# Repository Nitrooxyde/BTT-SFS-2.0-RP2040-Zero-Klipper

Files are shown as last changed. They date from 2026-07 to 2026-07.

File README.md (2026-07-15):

# BTT SFS 2.0 + RP2040‑Zero — Standalone USB Filament Sensor for Klipper







A **self‑contained, plug‑and‑play filament sensor module** for any Klipper printer:
a **BigTreeTech Smart Filament Sensor (SFS) 2.0** read by a **Waveshare RP2040‑Zero**
flashed as a standard **Klipper USB MCU**, both housed in a **one‑piece printed
receptacle**. One USB cable in, two native Klipper sensor objects out.

The SFS 2.0 exposes two signals — a **runout switch** (filament present / absent) and
a **motion encoder** (~1 pulse / 2.88 mm of filament travel). The RP2040‑Zero turns
both into first‑class Klipper objects:

- `[filament_switch_sensor sfs_switch]` → filament presence
- `[filament_motion_sensor sfs_motion]` → movement / no‑movement (clog, slip)

**Printed part also published on:**
[Printables](https://www.printables.com/model/1781579-btt-sfs-20-rp2040-zero-receptacle) ·
[Cults3D](https://cults3d.com/fr/mod%C3%A8le-3d/divers/standalone-usb-filament-sensor-for-klipper-btt-sfs-2-0-rp2040-zero-receptacl)

---

## Why a dedicated USB MCU for a filament sensor?

The usual way to wire an SFS is two signal lines back to the main board. Giving the
sensor **its own $3 microcontroller on USB** instead has real advantages:

- **Zero pins needed** on your main or toolhead board — useful when they're full,
  or when you don't want to run signal wires across the printer.
- **Board‑agnostic** — no board‑specific headers, voltage rails or pin mappings to
  figure out; the module brings its own MCU and its own 3.3 V, and works the same
  on every printer.
- **Plug‑and‑play** — one USB cable. Move the module between machines, or add it to
  a printer that was never wired for it.
- **Electrically self‑contained** — the SFS is powered from the Pico's 3V3 pin;
  no shared rails, no level‑shifting questions.
- **A single printed part** — sensor + MCU + mounting = one module on a 2020
  extrusion.

What you do with the two signals is up to your config — they are ordinary Klipper
sensor objects:

- **pause on runout** (`pause_on_runout: True` when you're ready),
- **clog / jam detection** — extruder commanded to move, encoder says nothing moves,
- **slip / under‑extrusion detection** — commanded‑vs‑wheel differential,
- **feed verification inside your own macros** — the motion state keeps updating
  even when the sensor is disabled (verified in Klipper source), which makes it a
  clean *“is filament actually moving?”* probe for any custom automation
  (multi‑material feeds, load/unload sequences, whatever you build).

---

## What's in this repo

| Path | Contents |
|---|---|
| [`docs/01-hardware.md`](docs/01-hardware.md) | SFS 2.0 + RP2040‑Zero specs, verified dimensions, BOM |
| [`docs/02-wiring.md`](docs/02-wiring.md) | SFS → Pico wiring, **the 3V3 rule**, pin map |
| [`docs/03-firmware-flashing.md`](docs/03-firmware-flashing.md) | Building & flashing Klipper on the RP2040‑Zero (Katapult) |
| [`docs/04-klipper-integration.md`](docs/04-klipper-integration.md) | `printer.cfg` blocks, safe bring‑up, usage |
| [`docs/05-cad-bracket.md`](docs/05-cad-bracket.md) | The printed receptacle: features, print settings, source |
| [`klipper/sfs.cfg`](klipper/sfs.cfg) | Ready‑to‑`[include]` Klipper config snippet |
| [`cad/SFS_Support_2020.stl`](cad/SFS_Support_2020.stl) | Print‑ready one‑piece receptacle (SFS 2.0 + RP2040‑Zero), definitive |
| [`cad/SFS20_Support_V4.FCStd`](cad/SFS20_Support_V4.FCStd) | FreeCAD source (direct modelling, not parametric — for adjustments) |
| [`firmware/`](firmware/) | Notes on the stock‑Klipper RP2040 build (no custom C) |

---

## Quick start (TL;DR)

1. **Print** `cad/SFS_Support_2020.stl` (ABS/ASA, 4 walls, 0.2 mm — see
   [docs/05](docs/05-cad-bracket.md)). Seat the pico in its cavity and **hot‑glue it
   at the four corners** — that's the retention method, and it doesn't move.
2. **Flash** the RP2040‑Zero with **stock Klipper, RP2040, USB, Katapult bootloader**
   ([docs/03](docs/03-firmware-flashing.md)).
3. **Wire** SFS → Pico: **VCC → 3V3 (never 5V)**, GND → GND, motion → **GP0**,
   switch → **GP1** ([docs/02](docs/02-wiring.md)).
4. **Add** the config below to `printer.cfg` (or copy `klipper/sfs.cfg` next to it
   and `[include sfs.cfg]`), fix the serial to *your* board, `FIRMWARE_RESTART`.

```ini
[mcu sfs]
serial: /dev/serial/by-id/usb-Klipper_rp2040_XXXXXXXXXXXXXXXX-if00

[filament_motion_sensor sfs_motion]
switch_pin: ^sfs:gpio0        # GREEN wire — motion encoder
detection_length: 2.88        # mm; SFS theoretical pulse pitch — tune at the bench
extruder: extruder
pause_on_runout: False        # bring-up safe: observe first, arm later

[filament_switch_sensor sfs_switch]
switch_pin: ^sfs:gpio1        # BLUE wire — runout switch
pause_on_runout: False
```

> ⚠️ **The two golden rules** (details in the docs):
> 1. **Power the SFS at 3.3 V.** The RP2040 is **not** 5 V‑tolerant (~3.8 V abs max).
>    5 V on the signal lines destroys the Pico.
> 2. **Keep the `^` pull‑ups.** The SFS outputs are open‑collector / switch‑to‑ground;
>    without an internal pull‑up they float.

---

## Placement

Anywhere on the filament path — that's the point of a self‑contained module. One
practical rule: **the closer to the extruder, the less slack** between the encoder
wheel and the drive gear, so the tighter `detection_length` can be and the earlier a
real clog or runout is flagged. And fit the **PTFE ID2/OD4 guide all the way into the
SFS bore on both ports** — without it, pushed filament buckles at the junction
(empirically confirmed; see [docs/01](docs/01-hardware.md)).

---

## Status

**Functional.** Built and running on a Voron 2.4: the receptacle prints and fits, the
RP2040‑Zero runs stock Klipper over USB (Katapult in place — no BOOT button needed for
reflash), and both sensor objects run in Klipper with the SFS powered at 3V3. The
definitive STL isn't claimed perfect — the pico is simply **hot‑glued at its four
corners** and doesn't move; a couple of optional refinements remain listed in
[docs/05](docs/05-cad-bracket.md).

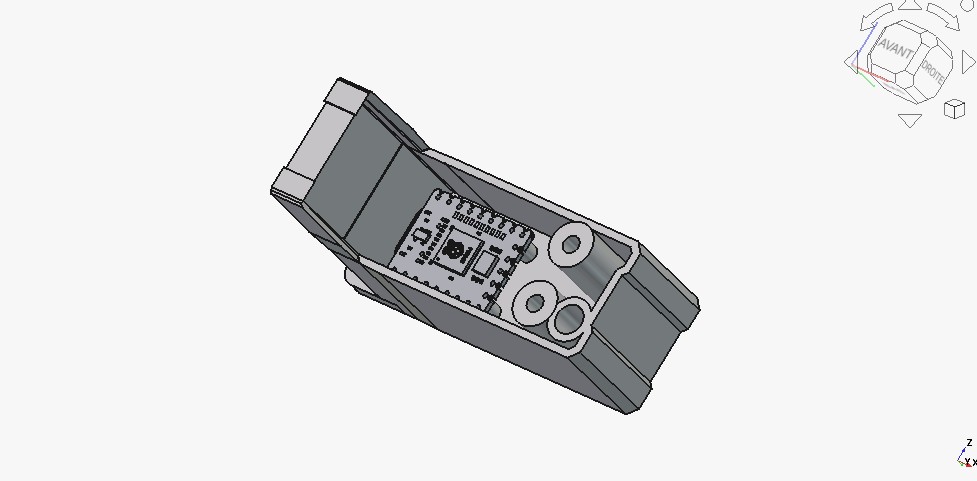
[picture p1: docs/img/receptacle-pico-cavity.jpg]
Receptacle with the RP2040-Zero seated in its cavity


See [`CHANGELOG.md`](CHANGELOG.md) for the build history.

---

## License

MIT — see [`LICENSE`](LICENSE). The BTT SFS 2.0 CAD model referenced in the docs is
BigTreeTech's own, distributed from their
[smart‑filament‑detection‑module](https://github.com/bigtreetech/smart-filament-detection-module)
repository under their terms.

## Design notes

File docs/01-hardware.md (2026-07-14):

# 01 — Hardware & specifications

## Bill of materials

| Qty | Part | Notes |
|-----|---|---|
| 1 | **BigTreeTech Smart Filament Sensor (SFS) 2.0** | Owned. Runout switch + motion encoder in one body. |
| 1 | **Waveshare RP2040‑Zero** | The USB MCU. 18 × 23.5 mm. **Not 5 V‑tolerant.** |
| 1 | Printed receptacle | `cad/SFS_Support_2020.stl` — houses both parts as one piece. |
| — | Hot glue | Fix the RP2040‑Zero in its cavity at the four corners. |
| 2 | **PC4‑M6** pneumatic fittings | Supplied with the SFS; one at each filament port. |
| 1 | **PTFE tube ID2 / OD4** | **Mandatory** guide into the SFS bore (see below). |
| 2 | **M3×12 button‑head** screws | Fix the receptacle to the SFS mounting face (self‑tapping into the SFS). The receptacle's counterbores are sized for button heads; the M3×6 supplied by BTT are too short through the receptacle. |
| 2 | M3 screws + T‑nuts | Fix the receptacle's tab to a 2020 extrusion. |
| 1 | USB‑C cable | RP2040‑Zero → Raspberry Pi. |
| — | Dupont / JST‑to‑bare wiring | SFS's two 3‑pin leads → RP2040‑Zero pads. |

> The BTT SFS 2.0 ships with 3× M3×6 screws, 2× PC4‑M6, and a PTFE ID2/OD4/L30 tube.

---

## BTT SFS 2.0 — verified specifications

Cross‑checked three ways: live measurement of the official STEP in FreeCAD ==
BTT STEP == BTT manual (`SFS V2.0 …_20231123.pdf`).

### Mechanical
- **Body:** X 53.5 · Y 30.3 · Z 27.3 mm (BTT official: 53.1 × 30.3 × 27.3). ~36 g.
- **Mounting face:** the large 53 × 27 face (normal +Y; net measured face area
  ≈ 1054 mm² — less than 53 × 27 because of the cutouts in the face).
- **3× M3 self‑tapping holes** in that face (pilot Ø2.7, head counterbore ≈ Ø5,
  blind into the plastic — **no inserts**; BTT supplies 3× M3×6):

  | Hole | X (mm) | Z (mm) |
  |------|--------|--------|
  | H1 | −61.7 | +6.7 |
  | H2 | −37.0 | +6.7 |
  | H3 | −37.0 | −5.7 |

  Spacing (BTT manual): **24.7 mm × 12.4 mm**, L‑shaped pattern.

- **Filament path = X axis** (inline pass‑through, bidirectional, 1.75 mm).
  M6 ports at **both ends** (accept the 2× PC4‑M6). The two ports are **diagonally
  offset** (the filament routes around the encoder): Port A ≈ (Y 22.0, Z +6.3),
  Port B ≈ (Y 36.9, Z −6.3). Internal bore: Ø1.75 guide → Ø3.4 groove → Ø4.6/5.0
  PTFE seat.

### The PTFE guide is not optional (empirically confirmed)
On **push** (loading), any un‑guided gap between the fitting and the internal bore
becomes a **buckling point** — the filament escapes at the junction instead of
advancing. Adding the **PTFE ID2/OD4 tube all the way into the internal bore** (not
just seated in the PC4‑M6) unblocked pushing in real use. Invisible on **pull**
(unloading), so easy to under‑estimate at design time — **fit it on both ports.**

### Electrical — **read this before wiring**
- **Rated voltage: 3.3 V – 5 V ONLY.** The manual (p.5 *Specifications*; p.25
  *Caution*) is explicit: *“any higher voltage will cause damage.”*
  → **The SFS works officially at 3.3 V** — the "5V" label on BTT's wiring diagrams
  is because their host boards are STM32 (5 V rail + 5 V‑tolerant FT pins), **not**
  a power‑supply requirement.
- **Detection length:** 2.88 mm (theoretical) per encoder pulse.
- **Cable:** 100 cm Y‑cable — 1× **4‑pin** at the sensor → 2× **3‑pin** to the board.
- **Wire colours / signals:**

  | Colour | Signal | Notes |
  |--------|--------|-------|
  | **RED** | VCC | **Feed 3.3 V for the RP2040** (see wiring). |
  | **BLACK** | GND | |
  | **BLUE** | Switch / runout | Active‑low, **pull‑up required**. |
  | **GREEN** | Motion / encoder | Toggles ~1 pulse / 2.88 mm, **pull‑up required**. |

  Both outputs behave as **switch‑to‑ground / open‑drain** → an **MCU pull‑up is
  mandatory** (the RP2040's internal pull‑ups do the job, hence the `^` prefix in
  the Klipper config).

- **On‑board LEDs** (on the label face): red = empty; blue blinking = extrusion OK;
  blue solid / off = no movement. Detection is internal (no external optical window).

> **Not documented / confirm visually if you rebuild the cable:** the exact JST
> series of the 4‑pin (XH 2.54 vs PH 2.0) and the exact cable‑exit face/orientation.

### Official CAD / manual
BigTreeTech repo: [`bigtreetech/smart-filament-detection-module`](https://github.com/bigtreetech/smart-filament-detection-module)
- `/V2.0/CAD/SFS V2.0 Model.STEP` (the model used to design the receptacle)
- `/V2.0/CAD/SFS V2.0 Bracket for Hurakan.STEP` (BTT's own reference bracket)
- `/V2.0/STL`, `/V2.0/Manual/… _20231123.pdf`

The STEP model was kept locally at `Voron/SFS_V2_0/SFS V2.0 Model.STEP` (≈25 MB, not
bundled here to keep the repo lean).

---

## Waveshare RP2040‑Zero — specifications

- PCB **18 × 23.5 × ~1.6 mm**, **USB‑C** on a short edge.
- RP2040 + 2 MB flash, WS2812 (NeoPixel) LED + power LED, **BOOT/RESET** button.
- 9 castellated pads per side + through‑pads.
- **Logic 3.3 V. NOT 5 V‑tolerant** (RP2040 absolute max ≈ 3.8 V on any pin).
  This is *the* reason the SFS must be powered at 3.3 V here.

> The RP2040‑Zero STEP found online (`crides/kleeb`) has **11 mm male header pins**
> (a low‑profile keyboard variant) — those are a modelling artifact; the real Zero is
> ~1.6 mm bare. They were ignored when designing the receptacle.

### Third RP2040 on the rig — serial hygiene
This Pico is the **third** RP2040 Klipper MCU on the printer (after the **BTT Eddy**
and the **Fysetc PIS**). All three share VID:PID `1d50:614e` (Manufacturer "Klipper",
Product "rp2040"). **Always identify each board by its unique serial** before editing
a `[mcu …]` block — see [docs/03](03-firmware-flashing.md).

Known serials on the reference rig:
- Octopus Pro (STM32): `usb-Klipper_stm32f446xx_300025001350324E31333220-if00`
- BTT Eddy (RP2040 #1): `usb-Klipper_rp2040_504450593844A21C-if00`
- Fysetc PIS (RP2040 #2): `usb-Klipper_rp2040_E663B03597314E27-if00`
- **This SFS Pico (RP2040 #3): `usb-Klipper_rp2040_5303284738FB5E1C-if00`**

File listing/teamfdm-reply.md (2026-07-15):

# TeamFDM reply — thread #6534 "BTT SFS 2.0 with Leviathan mainboard"

> À poster en réponse au thread (compte user). Ton : partage d'une alternative,
> humble. La réponse est AUTOSUFFISANTE (tout le how-to inline) ; le repo n'est
> qu'un pointeur final.
> https://www.teamfdm.com/forums/topic/6534-btt-sfs-20-with-leviathan-mainboard/

---

Nice find with PC0/PC1 + the neopixel 5V — glad it works.

For anyone landing here who'd rather not deal with board-specific pins and rails
at all, here's another route that works on any printer: give the sensor **its own
MCU**. A Waveshare **RP2040-Zero** (~$3) flashed as a plain Klipper USB MCU reads
both SFS signals, and the mainboard isn't involved at all — one USB cable to the
Pi.

**1. Flash the pico** — stock Klipper, nothing custom:

```
make menuconfig   # Micro-controller: Raspberry Pi RP2040 · Communication: USB
make
```

Hold BOOT, plug USB → the pico mounts as an `RPI-RP2` drive → copy
`out/klipper.uf2` onto it. Done. (Optional: put Katapult under it so future
reflashes don't need the button.)

**2. Wire the SFS to the pico** — 4 wires:

| SFS wire | → pico |
|---|---|
| RED (VCC) | **3V3** |
| BLACK (GND) | GND |
| GREEN (motion) | GP0 |
| BLUE (switch) | GP1 |

Power it from the pico's **3.3 V** pin: the SFS is rated 3.3–5 V per the BTT
manual (p.5 — the "5V" in BTT's wiring diagrams is just because their example
boards are 5V-tolerant STM32s), and the RP2040 itself is *not* 5V-tolerant, so
3.3 V keeps every signal safe whatever the output topology is. This also
sidesteps the diode-drop / sagging-rail questions entirely — the pico's 3V3
comes regulated from USB.

**3. Klipper config:**

```ini
[mcu sfs]
serial: /dev/serial/by-id/usb-Klipper_rp2040_XXXX-if00

[filament_motion_sensor sfs_motion]
switch_pin: ^sfs:gpio0        # motion encoder — clog/slip detection
detection_length: 2.88        # SFS pulse pitch; raise if false triggers
extruder: extruder
pause_on_runout: False        # observe first in Mainsail, arm later

[filament_switch_sensor sfs_switch]
switch_pin: ^sfs:gpio1        # runout switch
pause_on_runout: False
```

The `^` pull-ups are mandatory (both SFS outputs are switch-to-ground). Bring it
up with `pause_on_runout: False`, watch the two sensors in Mainsail while you
poke filament in and out, then arm the pause once you trust it. One gotcha if
you already have other RP2040s (Eddy, PIS…): they all share the same USB
VID:PID, so identify the right `/dev/serial/by-id/` entry by unplugging the pico
and seeing which one disappears.

I also designed a one-piece printed receptacle that holds the SFS + pico
together and mounts on a 2020 extrusion — that plus the full write-up
(flashing with Katapult, bring-up, assembly) is here if useful:
GitHub `Nitrooxyde/BTT-SFS-2.0-RP2040-Zero-Klipper` · Printables model 1781579.
Free/open (MIT + CC-BY), my own project.

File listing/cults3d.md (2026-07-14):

# Fiche Cults3D — prête à coller

> Fichiers à uploader : `cad/SFS_Support_2020.stl`
> Images : `docs/img/receptacle-pico-cavity.jpg`, `docs/img/receptacle-usbc-opening.jpg`
> **+ recommandé : 2–3 photos réelles** (pièce imprimée, module monté sur le 2020, câblage) — les photos réelles font ×3 sur les téléchargements.
> Catégorie : **Outil → Accessoires pour imprimante 3D**
> Prix : Gratuit (suggestion) · Licence : à choisir (suggestion : CC BY 4.0 — cohérent avec le repo MIT)

---

## Titre (FR)

Capteur de filament USB autonome pour Klipper — support BTT SFS 2.0 + RP2040-Zero

## Titre (EN)

Standalone USB Filament Sensor for Klipper — BTT SFS 2.0 + RP2040-Zero receptacle

---

## Description (FR)

**Un module capteur de filament complet, autonome, en une seule pièce imprimée — un câble USB et c'est branché.**

Ce support monobloc loge un **BigTreeTech Smart Filament Sensor 2.0** et un **Waveshare RP2040-Zero** flashé en MCU Klipper USB. Le pico lit les deux signaux du SFS (présence + mouvement) et les expose à Klipper comme objets natifs :

- `filament_switch_sensor` → présence du filament (runout)
- `filament_motion_sensor` → mouvement réel (bourrage, glissement, sous-extrusion)

**Pourquoi un MCU dédié ?**
- **Zéro pin nécessaire** sur votre carte principale ou toolhead
- **Un seul câble USB** — pas de fils de signaux à tirer à travers l'imprimante
- **Plug-and-play** : déplaçable d'une machine à l'autre
- Électriquement autonome : le SFS est alimenté en 3,3 V par le pico

**Caractéristiques du support :**
- Fixation sur **profilé 2020** (patte avec 2 trous M3 pour écrous T)
- Se visse sur la face de montage du SFS (2× M3×12 tête bombée, lamages intégrés)
- Cavité pour le RP2040-Zero avec ouverture USB-C au contour du connecteur
- Accès aux boutons BOOT/RESET (trous oblongs 3×5 mm)
- 2 ports filament M6 pour raccords PC4-M6

**Assemblage :** le pico se colle à la **colle chaude aux 4 coins** dans sa cavité (simple, ferme, démontable). Passez les guides PTFE ID2/OD4 jusqu'au fond des ports du SFS (indispensable en poussée).

**⚠️ Câblage : alimentez le SFS en 3,3 V uniquement** (le RP2040 n'est pas tolérant au 5 V). Câblage complet, flash Klipper/Katapult et config prête à l'emploi sur le GitHub :
👉 **github.com/Nitrooxyde/SFS2-RP2040-Klipper**

**Impression :** ABS/ASA (ou PETG), 0,2 mm, 4 périmètres, 30–40 % de remplissage. Supports uniquement sur les ouvertures selon l'orientation. STL vérifié étanche (59 488 facettes). Encombrement : 69 × 48 × 25 mm.

**BOM :** SFS 2.0 · RP2040-Zero · 2× M3×12 tête bombée · 2× M3 + écrous T · 2× PC4-M6 (fournis avec le SFS) · PTFE ID2/OD4 · câble USB-C · colle chaude.

Testé en réel sur une Voron 2.4.

---

## Description (EN)

**A complete, self-contained filament sensor module in a single printed part — one USB cable and you're wired.**

This one-piece receptacle houses a **BigTreeTech Smart Filament Sensor 2.0** and a **Waveshare RP2040-Zero** flashed as a Klipper USB MCU. The pico reads both SFS signals (presence + motion) and exposes them to Klipper as native objects:

- `filament_switch_sensor` → filament presence (runout)
- `filament_motion_sensor` → actual movement (clog, slip, under-extrusion)

**Why a dedicated MCU?**
- **Zero pins needed** on your main or toolhead board
- **One USB cable** — no signal wires across the printer
- **Plug-and-play**: move it between machines
- Electrically self-contained: the SFS runs on 3.3 V from the pico

**Receptacle features:**
- Mounts on a **2020 extrusion** (tab with 2× M3 holes for T-nuts)
- Screws onto the SFS mounting face (2× M3×12 button-head, counterbores included)
- RP2040-Zero cavity with a USB-C opening cut to the connector contour
- BOOT/RESET button access (3×5 mm oval holes)
- 2× M6 filament ports for PC4-M6 fittings

**Assembly:** hot-glue the pico at its **four corners** in the cavity (simple, firm, serviceable). Run the PTFE ID2/OD4 guides all the way into the SFS bore (mandatory when pushing filament).

**⚠️ Wiring: power the SFS at 3.3 V only** (the RP2040 is not 5 V-tolerant). Full wiring, Klipper/Katapult flashing and a ready-to-include config on GitHub:
👉 **github.com/Nitrooxyde/SFS2-RP2040-Klipper**

**Printing:** ABS/ASA (or PETG), 0.2 mm, 4 walls, 30–40 % infill. Supports only on the openings depending on orientation. STL verified watertight (59,488 facets). Footprint: 69 × 48 × 25 mm.

**BOM:** SFS 2.0 · RP2040-Zero · 2× M3×12 button-head · 2× M3 + T-nuts · 2× PC4-M6 (supplied with the SFS) · PTFE ID2/OD4 · USB-C cable · hot glue.

Tested for real on a Voron 2.4.

---

## Tags

`klipper` `voron` `filament sensor` `runout sensor` `btt sfs` `rp2040` `smart filament sensor` `2020 extrusion` `3d printer accessory` `filament runout`

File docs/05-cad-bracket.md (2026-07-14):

# 05 — The printed receptacle

A **one‑piece receptacle** that holds the **SFS 2.0** and the **RP2040‑Zero** together
and mounts to a **2020 extrusion** — so the whole sensor module is a single printed
part with one USB cable leaving it.

- **Print file:** [`cad/SFS_Support_2020.stl`](../cad/SFS_Support_2020.stl)
  — binary STL, **59 488 facets**, **watertight** (verified: 0 open/non‑manifold
  edges, edges = 1.5 × facets exactly), volume ≈ 13.7 cm³.
- Bounding box: **69.3 mm** (incl. the 2020 tab) × **47.5 mm** × **24.7 mm**.
- **Source:** [`cad/SFS20_Support_V4.FCStd`](../cad/SFS20_Support_V4.FCStd)
  — ⚠️ **direct BREP modelling, not a parametric feature tree**: there are no
  dimensions to edit in a tree. Provided for those who want to adjust the geometry
  by direct modelling.

Receptacle with the RP2040-Zero seated
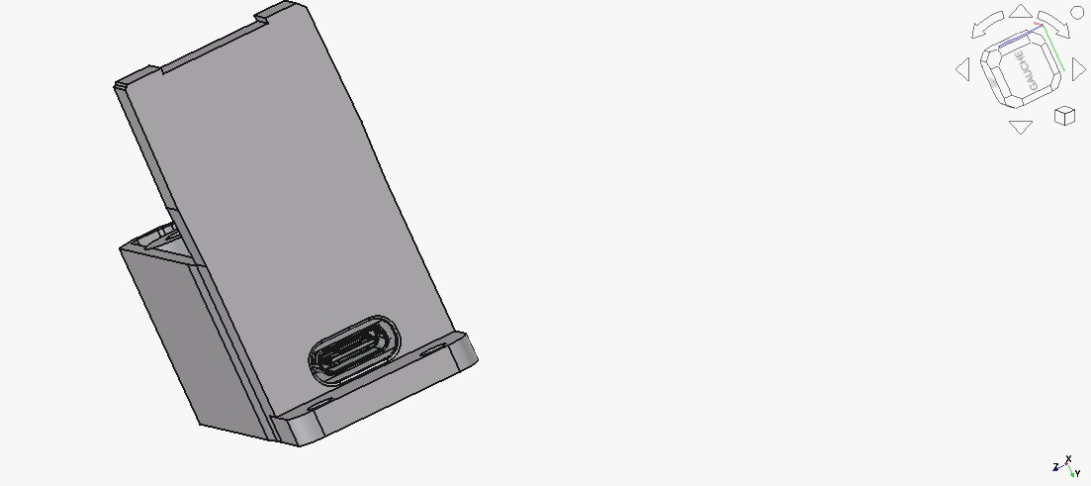
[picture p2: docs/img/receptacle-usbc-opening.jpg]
USB-C opening in the end wall


> Design note: the part was modelled face by face against the real SFS/RP2040 STEP
> geometry (an earlier patch‑on‑patch attempt was scrapped and rebuilt from scratch).

## Features

- **RP2040‑Zero cavity** at the −X end, USB‑C exposed through an opening cut to the
  **real connector contour** (obround; the tight axis is the ~3.4 mm connector
  height — see *Known‑open items* below).
- **2× M6 filament ports** matching the SFS bore, for the PC4‑M6 fittings.
  → Run the **PTFE ID2/OD4** guide all the way into the SFS bore on both
  (see [docs/01](01-hardware.md)).
- **2× M3 mounting tunnels** through the SFS mount face — Ø3.4 clearance shaft with a
  **flat Ø6 counterbore** for M3×12 button‑head screws (button head = flat‑bottom
  counterbore, never a conical countersink), ~6 mm thread engagement into the SFS.
- **2× BOOT/RESET access holes**, **ovalised 3.0 × 5.0 mm**, aligned to the Pico's
  KEY1/KEY2 buttons.
- **4× PCB standoffs**, trimmed to seat exactly on the board's top face
  (**Y = 56.60 mm + 0.10 mm clearance**) — no bottoming‑out on the PCB.
- **Reinforced outer wall ≈ 3.45 mm** for rigidity.
- **2020 mounting tab** on the −X face: extended +20 mm in X, **2× M3 through‑holes**
  for T‑nut mounting to the extrusion.
- Front mouth aligned to a single plane with a small **R0.3 fillet** on the front
  contour edges.

## Suggested print settings

This is a functional structural bracket, so print it strong:

| Setting | Value |
|---|---|
| Material | **ABS or ASA** (matches the toolhead environment; PETG works too) |
| Layer height | 0.2 mm |
| Walls / perimeters | **4** (wall count is the real strength lever, not layer height) |
| Infill | 30–40 % |
| Supports | Only where the USB‑C / port / button openings overhang, depending on orientation |

> Orientation is not prescriptive — pick the face that puts the mounting tab and the
> filament ports on clean surfaces and minimises support inside the pico cavity.

## Assembly

- Seat the RP2040‑Zero in its cavity (USB‑C through the end‑wall opening) and
  **hot‑glue it at the four corners** — that's the designed retention: simple, holds
  firmly, and stays serviceable (hot glue peels off if you ever need the board out).
- Screw the receptacle to the SFS mounting face with the 2× M3×12 button‑heads, and
  to the 2020 extrusion through the tab with M3 + T‑nuts.
- Run the PTFE ID2/OD4 guides into the SFS bore on **both** ports (see
  [docs/01](01-hardware.md)).

## Known‑open items / optional refinements

The part is **functional** (the author: *"it's not perfect"* — but it does the job);
a few optional refinements were deliberately left open:

- **Positive pico retention** — the cavity is open by design; hot glue at the four
  corners is the intended fix (see *Assembly*). Add a clip/lid in the source if you
  want a mechanical retention instead.
- **USB‑C opening clearance** — the truly tight axis is the **connector height**
  (~3.4 mm opening vs ~3.16 mm connector, ≈0.2 mm play); the long axis is already
  ~2× the connector width. If your cable's overmold binds, open the *height* axis
  slightly in the source (an earlier tweak widened the long axis, which changes
  nothing — see `CHANGELOG.md`, 07‑04).
- **−Y mouth flush lip** — a ~0.01 mm residual skin (1/20 of a layer, not sliced) was
  left because OCC refused a perfectly coincident cut; reconstruct the −Y face as a
  separate parametric frame if you want a geometric flush.
- Minor plane‑alignment nits (floor/ceiling ±10.728 vs ±10.7) — cosmetic.

## ⚠️ Maintainer note — regenerating the STL
When rebuilding/exporting from the source: **always re‑read the exported file on disk**
(facet count / size / date) to prove the content before printing — do not trust the
"export succeeded" message alone (a stale STL once got printed for 1h40 this way).
If exporting from a snap‑packaged FreeCAD, note the export lands in the snap sandbox
(`~/snap/freecad/<rev>/…`), not your real home.

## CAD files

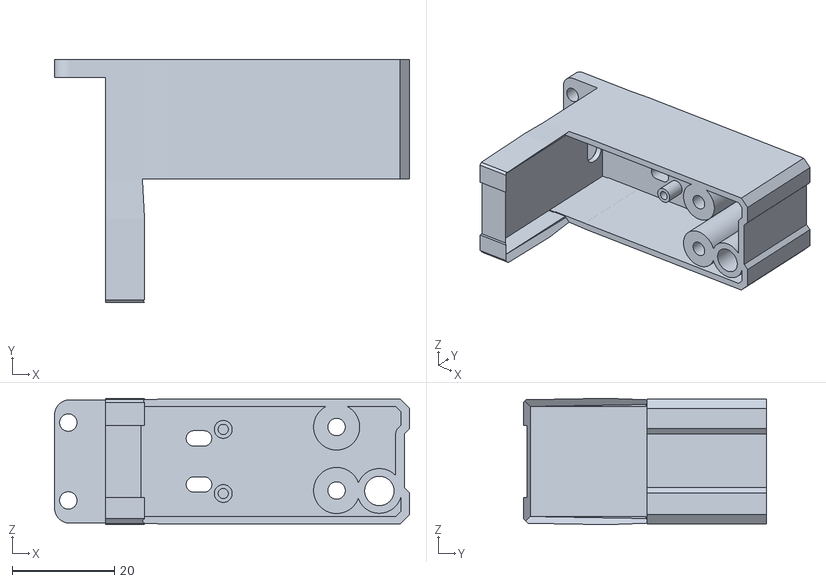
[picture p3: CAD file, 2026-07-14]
cad/SFS_Support_2020.stl
69.3 x 47.5 x 24.7

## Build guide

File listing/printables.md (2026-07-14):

# Printables listing — ready to paste

> Files to upload: `cad/SFS_Support_2020.stl`
> Images: `docs/img/receptacle-pico-cavity.jpg`, `docs/img/receptacle-usbc-opening.jpg`
> **+ recommended: 2–3 real photos** (printed part, module mounted on the 2020, wiring) — real photos massively boost downloads.
> Category: **3D Printers → Printer Accessories**
> License: pick in the dropdown (suggestion: **CC BY 4.0**, consistent with the MIT repo)

---

## Title

Standalone USB Filament Sensor for Klipper — BTT SFS 2.0 + RP2040-Zero Receptacle

## Summary (short field)

One-piece receptacle for a BTT SFS 2.0 + RP2040-Zero running Klipper over USB. One cable in → native runout + motion sensors in Klipper. Zero pins needed on your boards. Mounts on 2020 extrusion.

---

## Description

**A complete, self-contained filament sensor module in a single printed part — one USB cable and you're wired.**

This receptacle houses a **BigTreeTech Smart Filament Sensor 2.0** and a **Waveshare RP2040-Zero** flashed as a standard Klipper USB MCU. The pico reads both SFS signals and exposes them to Klipper as native objects:

- `filament_switch_sensor` → filament presence (runout)
- `filament_motion_sensor` → actual movement (clog, slip, under-extrusion detection)

### Why a dedicated MCU?

- **Zero pins needed** on your main or toolhead board
- **One USB cable** — no signal wires across the printer
- **Plug-and-play** — move it between machines, or retrofit a printer never wired for it
- Electrically self-contained: the SFS runs on 3.3 V from the pico

### Receptacle features

- Mounts on a **2020 extrusion** (tab with 2× M3 holes for T-nuts)
- Screws onto the SFS mounting face — 2× M3×12 button-head, flat counterbores included
- RP2040-Zero cavity with a USB-C opening cut to the real connector contour
- BOOT/RESET button access holes (3×5 mm ovals)
- 2× M6 filament ports for the PC4-M6 fittings supplied with the SFS

### Assembly

1. Seat the pico in its cavity (USB-C through the end-wall opening) and **hot-glue it
   at the four corners** — simple, firm, and serviceable.
2. Screw the receptacle to the SFS with 2× M3×12 button-head.
3. Mount on the 2020 with M3 + T-nuts.
4. Run the **PTFE ID2/OD4 guides all the way into the SFS bore** on both ports —
   mandatory when pushing filament, otherwise it buckles at the junction.

### Wiring & Klipper config

**⚠️ Power the SFS at 3.3 V only** — the RP2040 is **not** 5 V-tolerant.
Motion → GP0, switch → GP1, internal pull-ups.

Full wiring guide, Klipper/Katapult flashing steps and a ready-to-include
`sfs.cfg` are on GitHub:
**https://github.com/Nitrooxyde/SFS2-RP2040-Klipper**

### BOM

| Qty | Part |
|-----|---|
| 1 | BigTreeTech SFS 2.0 |
| 1 | Waveshare RP2040-Zero |
| 2 | M3×12 button-head screws |
| 2 | M3 screws + T-nuts (2020 mounting) |
| 2 | PC4-M6 fittings (supplied with the SFS) |
| — | PTFE tube ID2/OD4 |
| 1 | USB-C cable |
| — | Hot glue |

Tested for real on a Voron 2.4. STL verified watertight (59,488 facets).
Footprint: 69 × 48 × 25 mm.

---

## Print settings (structured fields)

- **Printer:** any (designed on a Voron 2.4)
- **Nozzle:** 0.4 mm
- **Layer height:** 0.2 mm
- **Material:** ABS / ASA (PETG works)
- **Perimeters/walls:** 4
- **Infill:** 30–40 %
- **Supports:** only on the USB-C / port / button openings, depending on orientation
- **Brim:** optional

## Tags

klipper, voron, filament-sensor, runout-sensor, btt-sfs, rp2040, smart-filament-sensor, 2020-extrusion, printer-accessory, filament-runout

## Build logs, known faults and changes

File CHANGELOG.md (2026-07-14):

# Changelog / build history

Chronology of how the SFS 2.0 + RP2040‑Zero USB filament sensor came together
(reference build: Voron 2.4, Raspberry Pi host).

## 2026‑07‑02 — Decision & scope
- Chose to read the **BTT SFS 2.0** with a dedicated **RP2040‑Zero flashed as a
  Klipper USB MCU** — a self‑contained, plug‑and‑play sensor module instead of wiring
  the two signals back to the main board. Two signals →
  `[filament_motion_sensor]` (clog/slip) + `[filament_switch_sensor]` (presence).
- Imported the official **SFS V2.0 Model.STEP** and the RP2040‑Zero model in FreeCAD.
  Cross‑verified SFS dimensions three ways (live measurement == STEP == manual).

## 2026‑07‑02 → 07‑03 — Receptacle CAD
- First bracket attempt (boolean patch‑on‑patch) was **rejected** and the part
  **rebuilt from scratch parametrically**, face by face, as `REC_body_v1` in
  `SFS20_Support_V2.FCStd`.
- Built up: pico cavity, USB‑C opening (real connector contour), 2× M6 filament ports,
  2× M3 mounting tunnels (Ø6 flat counterbore for M3×12 button‑head), 2× BOOT/RESET
  access holes, 4× PCB standoffs, mouth alignment + R0.3 front fillet.

## 2026‑07‑03 — STL exports
- `REC_body_v2.stl` (64 160 facets) exported.
- Later superseded by the re‑exported `REC_body_v1.stl` (see 07‑04).

## 2026‑07‑04 — Firmware, wiring decision, refinements
- **SFS spec verified from the official manual (PDF):** rated **3.3–5 V**, detection
  length **2.88 mm**. Conclusion: power the SFS at **3.3 V** for the (non‑5 V‑tolerant)
  RP2040.
- **Pin mapping decided:** motion → **GP0**, switch → **GP1**, pull‑ups on both.
- **RP2040‑Zero flashed** stock Klipper USB + Katapult →
  serial `usb-Klipper_rp2040_5303284738FB5E1C-if00`. Re‑tested OK.
- Receptacle refined: M3 tunnels' counterbores corrected, outer wall reinforced to
  ~3.45 mm, BOOT/RESET holes ovalised 3.0 × 5.0, PCB standoffs re‑trimmed to seat on
  the board face (Y 56.60 + 0.10 clearance), **2020 mounting tab** added.
- `printer.cfg` bring‑up block prepared (safe mode, `pause_on_runout: False`).
- **`REC_body_v1.stl` re‑exported** (63 536 facets, watertight) — print file at the
  time, since replaced by the definitive `SFS_Support_2020.stl` (see 07‑15).
- USB‑C opening widened by 0.3 mm (commit `elargir_usbc_+0.3`); later noted the
  *tight* axis is the ~3.4 mm connector‑height axis, not the one widened.

## 2026‑07‑05 — Deployed
- **Sensor module deployed on the reference printer at VCC 3.3 V, both sensor objects
  enabled in Klipper.**
- `sfs_motion` confirmed as the *"advances vs slips"* discriminator during manual
  load/unload jogs (its motion state updates even when the sensor is `ENABLE=0`).
- Confirmed empirically: **PTFE ID2/OD4 guide into the SFS bore is mandatory** on push
  (without it the filament buckles at the junction).

## 2026‑07‑15 — Definitive STL
- **`SFS_Support_2020.stl` delivered by the author** with final corrections —
  59 488 facets, watertight (0 open edges), 69.3 × 47.5 × 24.7 mm, ≈ 13.7 cm³.
  Replaces `REC_body_v1.stl`.
- FreeCAD source updated to **`SFS20_Support_V4.FCStd`** (direct BREP modelling,
  not a parametric feature tree — provided for adjustments).
- Retention method settled: the RP2040‑Zero is **hot‑glued at its four corners**
  in the open cavity — simple and it doesn't move.
- CAD screenshots added to `docs/img/`.

## 2026‑07‑15 — This repo
- Consolidated hardware, wiring, firmware, Klipper integration and CAD into a
  standalone, documented repository. Bracket bundled as print‑ready STL + FreeCAD
  source; Klipper config as a ready‑to‑include snippet.
- Documentation reframed: the module is a **generic standalone USB filament sensor** —
  application‑specific context from the reference printer (multi‑material feed
  experiments) removed from the docs; what you build on the two signals is up to
  your config.

---

### Notes on state
- The receptacle is **functional**; the FreeCAD source (`SFS20_Support_V4.FCStd`) and
  the definitive print‑ready STL (`SFS_Support_2020.stl`) are both in `cad/`.
- The config to use is [`klipper/sfs.cfg`](klipper/sfs.cfg) — adapt the serial to your
  board.

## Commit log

2026-07-14 Ship the definitive STL + V4 source + assembly method + screenshots
    - cad/SFS_Support_2020.stl: definitive print file from the author (59488
    facets, verified watertight: 0 open edges, edges=1.5x facets; 69.3x47.5x24.7
    mm, ~13.7 cm3). Replaces REC_body_v1.stl.
    - cad/SFS20_Support_V4.FCStd: updated source; documented as direct BREP
    modelling (not a parametric feature tree), provided for adjustments.
    - Assembly documented: RP2040-Zero hot-glued at its four corners in the open
    cavity (the designed retention — simple, firm, serviceable).
    - docs/img/: two CAD screenshots (pico seated in cavity, USB-C opening),
    referenced from README and docs/05.
    - README/docs/01/docs/05/CHANGELOG updat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
    [REC_body_v1.stl, SFS_Support_2020.stl]
2026-07-14 Add ready-to-paste Cults3D (FR+EN) and Printables listings
    Both point to the GitHub repo for wiring/flashing/config; include BOM,
    print settings, assembly (hot-glue pico), tags, and upload checklists.
2026-07-15 README: link the published Printables and Cults3D listings
2026-07-15 README: cite the mainboard-quirks pain point the module eliminates
    Real-world example: SFS 2.0 on a Leviathan — dead dedicated header, sagging
    3.3V rail, 5V reading 4.5V after a diode drop, GPIO hunting (TeamFDM #6534).
2026-07-15 README: neutral board-agnostic wording (no board called out); humbler forum reply
2026-07-15 teamfdm reply: self-contained how-to (flash, wiring, config inline); repo as footnote only
